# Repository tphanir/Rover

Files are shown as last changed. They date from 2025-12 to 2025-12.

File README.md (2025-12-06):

# Rover Genesis

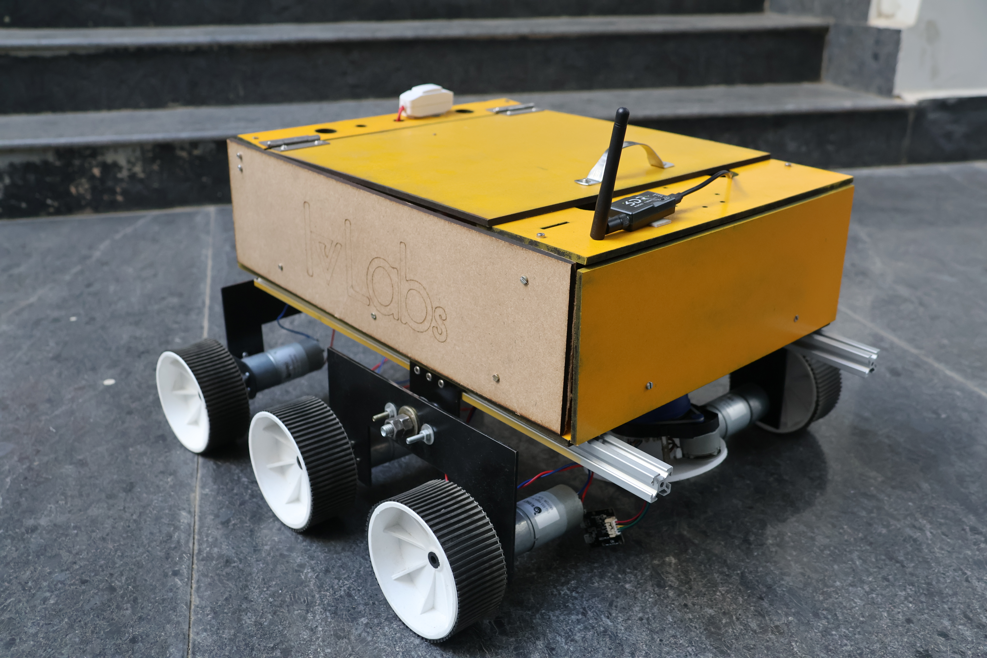
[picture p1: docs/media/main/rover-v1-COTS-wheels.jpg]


**Genesis** is a semi-autonomous rover platform designed for outdoor exploration, GPS-guided waypoint navigation, and obstacle avoidance. The system operates using a hybrid architecture: high-level computer vision and decision-making are handled by an **Nvidia Jetson Nano**, while real-time motor control and sensor integration are managed by an **Arduino Mega**.

The platform features a custom Base Station for telemetry and control, as well as voice-command capabilities for hands-free operation.

## Table of Contents

1. [System Architecture](#system-architecture)
2. [Project Structure](#project-structure)
3. [Key Features](#key-features)
4. [Hardware Specifications](#hardware-specifications)
5. [Getting Started](#getting-started)
6. [Usage](#usage)
7. [Documentation](#documentation)
8. [Contributors](#contributors)

---

## System Architecture

The software is divided into two primary nodes communicating via radio telemetry:

1.  **Onboard System:** Runs on the rover. Handles autonomous navigation logic, depth-camera processing, and hardware actuation.
2.  **Base Station:** Runs on a host laptop. Provides a GUI for manual control, mode switching (Auto/Manual), and live status monitoring.

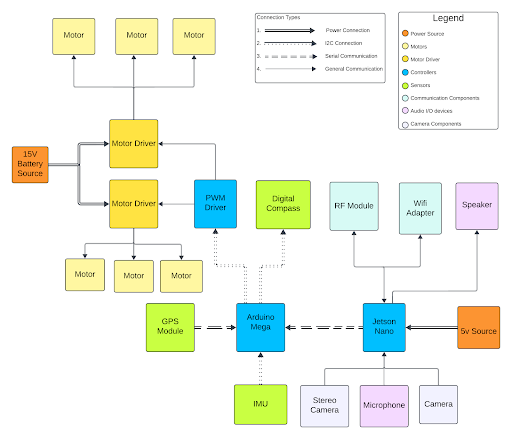
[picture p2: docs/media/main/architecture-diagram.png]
Architecture Diagram


---

## Project Structure

This repository is organized as follows:

* **`base_station/`**: Ground control software.
    * `gui/`: Contains Tkinter interface logic and configuration.
    * `run_station.py`: Entry point for the laptop control application.
* **`onboard/`**: The primary rover software (Jetson Nano).
    * `controls/`: Algorithms for GPS navigation (`gps.py`) and autonomous logic (`fullauto.py`).
    * `handlers/`: Interfaces for Serial communication (`mega.py`) and Manual control mapping.
    * `modules/`: Drivers for the RealSense camera (`camera.py`).
    * `main.py`: Entry point for the rover.
* **`extra/`**: Experimental scripts and isolated tests.
    * `detection/`: Standalone scripts for testing obstacle avoidance algorithms.
    * `imu/`: Visualization tools for sensor data.
* **`pcb/`**: Hardware design files.
    * Contains schematics and Gerber files for the custom power distribution board.
* **`docs/`**: Detailed documentation and media assets.

---

## Key Features

* **GPS Guided Navigation:** autonomous traversal to waypoints using the Haversine formula and magnetometer heading correction.
* **Vision-Based Avoidance:** Uses an Intel RealSense D415 to detect obstacles. The pipeline utilizes Canny Edge Detection and depth thresholding to identify hazards.
* **Voice Interaction:** Supports voice commands (e.g., "Stop", "Go") and Q&A using NLP models.
* **Telemetry:** Long-range 433MHz radio link for status updates and manual override.
* **Custom Electronics:** Features a dedicated PCB for efficient power management between the computing units and high-torque motors.

---

## Hardware Specifications

* **Compute:** Nvidia Jetson Nano (4GB) & Arduino Mega 2560
* **Vision:** Intel RealSense D415 Depth Camera
* **Sensors:** Ublox Neo M8N GPS, HMC5883L Magnetometer
* **Actuation:** BTS7960 43A Motor Drivers
* **Communication:** 3DR 433MHz Telemetry Radio
* **Power:** 4S LiPo Battery (14.8V)

For a detailed breakdown of the electronics, refer to `docs/hardware.md`.

---

## Prerequisites

* **Hardware:** A fully assembled Genesis rover and a host laptop.
* **Operating System:** Ubuntu 18.04 (Jetson Nano), Linux/Windows/MacOS (Base Station).
* **Python:** Version 3.6 or higher.

---

## Usage

### 1. Launching the Base Station
On your control laptop, connect the telemetry radio and run:

```bash
cd base_station
python3 run_station.py
```

### 2. Launching the Rover
SSH into the Jetson Nano or connect via terminal. Ensure the Arduino is connected via USB. Run:

```bash
cd onboard
python3 main.py
```

### 3. Operation Modes
* **Manual:** Use the WASD keys on the Base Station to drive the rover.
* **Auto:** Upload GPS coordinates via the GUI. The rover will calculate the bearing and distance, navigating autonomously while avoiding obstacles.

---

## Documentation
For deep dives into the specific algorithms and hardware designs, please refer to the `docs/` folder:

* **[Software Manual](docs/software.md):** Detailed explanation of the navigation math (Haversine), logic flows, and Vision pipeline.
* **[Hardware Guide](docs/hardware.md):** Wiring diagrams and component specifics.
* **[PCB Schematics](pcb/schematic.pdf):** Circuit diagrams for the custom board.

---

## Contributors
* Aiden Ross D'souza
* Telukunta Phani Raj
* Koyaneni Yashwant
* Shubham Pandere
* Yuvraj Gupta

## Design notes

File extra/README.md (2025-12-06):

# Extra / Experiments

This directory contains **miscellaneous experiments** and legacy code developed during the evolution of the **Rover** project.  
While not part of the main rover control system, these files served as important learning points for specific features, hardware integration, and testing.

---

## Overview

### `detection/`
- Contains multiple programs (`obstacle_x.py`) developed to test various Computer Vision (CV) methods for obstacle detection.
- **Requirement:** Intel RealSense camera.

### `imu/`
- Contains the IMU visualization and orientation tracking code (`imu.py`).
- Visualizes 3D motion of the rover (roll, pitch, yaw) using **PyOpenGL** and **pygame**.
- **Modes:**
  - **Connected:** Reads live orientation data from the ESP32-IMU.
  - **Disconnected:** Runs in simulation mode showing a static/rotating cube.

### `legacy/`
- Contains older versions of the main loop or scratchpad code (`main.py`) used for testing logic before integration into the `onboard` system.

### `serial/`
- Contains serial communication testing code (`radio.py`).
- Used to verify reading and relaying command data from the control computer (Base Station) via LoRa/Radio.

### `voice/`
- Contains standalone voice recognition tests (`voice.py`).
- Used to debug the voice command subsystem in isolation.

---

## Note
- None of these modules are required for the main rover execution.

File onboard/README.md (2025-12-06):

# Rover Main System

This directory contains the main control software for the Rover project.  
It integrates all modules needed for manual, semi-autonomous, and fully autonomous navigation, gps-based navigation.

---

## Overview

### controls/
Contains programs handling different control modes:
- **fullauto.py** — Full autonomous navigation using Camera. 
- **gps.py** — GPS control instruction program.
- **semiauto.py** — Semi-autonomous control combining user input with automation.

### handlers/
Handles inputs, communication, and command processing:
- **manual.py** — Manual (keyboard/joystick) control.  
- **mega.py** — Arduino Mega communication handler.  
- **serial.py** — Serial communication between base station and rover.  
- **voice.py** — Voice command handling.

### helpers/
- **forward.py** — Forwards messages from Arduion mega to base_station.

### main.py
- Main entry point — connects all modules for complete rover operation.

### modules/
- **Camera.py** — Camera handling and video stream processing.

### scripts/
- **docker.sh** — Docker script for setting up Jetson-Voice modules.
- **echo.sh** — Simply echoes the VoiceNav/data.txt content.

### voice_nav/
- **main.py** — Voice navigation control.  
- **data.txt** — Voice data or recognized commands.  
- **echo.sh** — Voice test script.

---

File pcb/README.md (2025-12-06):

# PCB Design & Hardware

This directory contains the manufacturing files for the custom **Power Distribution and Control Board** used in Rover Genesis 2. This board manages power delivery from the battery to the Jetson Nano, Arduino Mega, and motor drivers.

## File Overview

### `schematic.pdf`
The complete circuit diagram of the custom board. It details:
* **Power Regulation:** Buck converters for 5V (Jetson/Arduino) and 12V/VIN (Motors).
* **Pinout Connections:** Headers for connecting the Jetson Nano, Arduino, and sensors.
* **Protection:** Fuses and reverse polarity protection logic.

### `gerbers.zip`
The zipped Gerber files required for manufacturing the Printed Circuit Board (PCB). This file includes:
* **Copper Layers:** Top (GTL) and Bottom (GBL).
* **Solder Mask:** Top (GTS) and Bottom (GBS).
* **Silkscreen:** Component labels and logos (GTO).
* **Drill Files:** Hole locations and sizes (DRL).

## Fabrication Instructions

To manufacture this board, upload `gerbers.zip` to a PCB fabrication service (e.g., JLCPCB, PCBWay, OSH Park).

## Visuals
For 2D and 3D renders of this board, see the [docs/media/pcb](../docs/media/pcb) directory.

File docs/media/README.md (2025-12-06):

# Project Media & Assets

This directory contains visual assets and debug images used to document the hardware design and software logic.

## Directory Overview

### cad/ (Mechanical Design)
Contains renders from the CAD software used to model the chassis.
* **rover-v2-isometric-cad-model.png**: An angled 3D view of the complete rover.
* **rover-v2-top-cad-model.png**: A top-down view showing component placement.

### main/ (System Overview)
General images related to the rover architecture.
* **architecture-diagram.png**: A block diagram connecting the Base Station, Jetson Nano, and Arduino.
* **rover-v1-COTS-wheels.jpg**: A photograph of the assembled rover with COTS wheels.
* **rover-v1-3D-printed-wheels**: A photograph of the assembled rover with custom 3D printed wheels.

### obstacle_detection/ (Computer Vision Debug)
Visual outputs from the autonomous navigation module showing how the rover interprets depth data.
* **rgb-bbox.png**: Color camera feed with detected objects.
* **depth-bbox.png**: Depth map showing distance to objects.
* **threshold-map.png**: Binary image highlighting areas that are too close.
* **canny-edges.png**: Edge detection results used to define object boundaries.
* **obstacle-map.png**: The final processed map used for decision making.
* **decision-rotate-left.png**: Visualization of the logic deciding to turn left.

### pcb/ (Electronics)
Schematics and renders of the custom Power Distribution PCB.
* **2D-schematic-of-PCB-design.png**: The layout view of the PCB traces.
* **3D-schematic-of-PCB-design.png**: A 3D render of the manufactured board.

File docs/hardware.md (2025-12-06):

# Hardware & Electronics Specification

This document details the hardware architecture of the **Genesis** rover.

## Suspension System – Triple Bogie Configuration

The rover uses a **triple bogie suspension system** on each side, enabling high stability and smooth mobility over rough terrain. Each bogie can move independently, ensuring continuous wheel contact with uneven surfaces.

### Key Advantages

- **Terrain Adaptability:** Independent bogie movement keeps all wheels grounded, improving traction on rocks, slopes, and irregular surfaces.
- **Even Load Distribution:** Weight is shared across multiple wheels, reducing stress on individual components and increasing overall durability.
- **High Slope Stability:** The lowered center of mass and balanced weight distribution allow safe navigation on slopes up to **45°**.
- **Obstacle Handling:** The suspension can climb small obstacles and traverse gaps without wheel lift or instability.
- **Shock Absorption:** The interconnected bogies naturally dampen shocks, protecting onboard electronics and extending component lifespan.

## Wheel Design Comparison

Two wheel designs were evaluated: a **COTS (Commercial Off-The-Shelf) wheel** and an **in-house 3D-printed wheel**.

<p float="left">
  
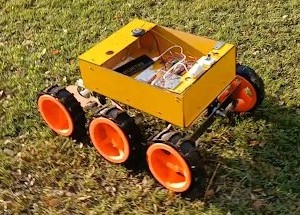
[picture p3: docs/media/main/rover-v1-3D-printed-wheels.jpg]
  
</p>

A summary of their performance is shown below:

### Table: Off-The-Shelf vs 3D-Printed Wheels

| Parameter | COTS Wheel | 3D-Printed Wheel |
| --- | --- | --- |
| Diameter | 10 cm | 22 cm |
| Width | 4.4 cm | 6 cm |
| Rover Speed | 20 cm/s | 44 cm/s |
| Grousers | Small | Large |
| Grip | Handles slopes up to 50° | Handles slopes up to 30° |
| In-Place Rotation | Smooth | Wobbly (Due to large grousers) |

## Electronic Components

The table below shows a comprehensive list of all electronic components used.

| Component | Purpose / Function |
| --- | --- |
| 14.8 V 4-cell Lithium polymer battery | Supplies power to the motor drivers |
| 5V Power Bank | Powers the Jetson Nano |
| Power Distribution Board | Distributes electrical power from the main source to the motor drivers |
| Customised PCB | Ensures stable connections between sensors and controllers |
| Jetson Nano (Student Developer Kit) | Primary processing unit for obstacle detection, voice commands, DetectNet, live streaming |
| Arduino Mega 2560 | Handles PWM signals, processes sensor data, communicates with peripherals |
| BTS7960 Motor Driver | Controls the movement of six motors |
| Orange OG555 DC Motor | Drives the rover’s wheels for movement and navigation |
| Ublox Neo M8N GPS Module | Provides real-time geolocation data for navigation and path planning |
| HMC5883L Magnetometer | Determines rover heading and maintains accurate orientation |
| YD LiDAR (2D LiDAR Sensor – 360° Scanning, 8m Distance) | Captures depth information for obstacle detection in a 2D plane |
| Intel RealSense D415 Stereo Camera | Captures depth information for obstacle detection in a 3D sphere |
| PlayStation Eye Camera | Provides visual feed for data collection and monitoring |
| 3DR 433 MHz Radio Telemetry | Enables wireless communication |
| Wi-Fi Adapter | Facilitates remote communication with the rover |
| Bestor Microphone | Records audio for audio-based functionalities |
| Speaker | Outputs audio feedback |

## Hardware Components

The table below shows a comprehensive list of all structural components used.

| Component | Material / Design | Features |
| --- | --- | --- |
| Chassis | High-quality acrylic held with L clamps | Durable and visually appealing design |
| Main Framework | 20×20 mm aluminum extrusions | Lightweight yet robust; maintains structural integrity while keeping weight manageable |
| Freely Moving Joints | Flanged ball bearings | Reduces friction and wear; allows smooth, efficient movement |
| Side Bogie Stability | Carbon fiber rods | High strength-to-weight ratio; reinforcement without added weight |
| Wheels | Durable COTF material (10 cm × 4 cm) | Ensures stability and smooth navigation across various terrains |
| Chassis Base | 5 mm MDF board | Adds strength and stability; reliable support for components |
| Side Bogie Construction | Mild steel | High strength and resistance to bending; improves slope-climbing capability |

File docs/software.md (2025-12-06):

# Genesis Rover: Software & Algorithms Manual

This document details the software stack, algorithms, and logic flows powering the **Genesis** rover. It covers system architecture, autonomous navigation, AI interaction, and control logic.

## Table of Contents
1. [System Architecture](#1-system-architecture)
2. [Autonomous Navigation Algorithms](#2-autonomous-navigation-algorithms)
3. [AI & Interaction Stack](#3-ai--interaction-stack)
4. [Control Logic & Data Flow](#4-control-logic--data-flow)
5. [Streaming](#5-streaming)

---

## 1. System Architecture
The software is distributed across three processing units:

* **Nvidia Jetson Nano:** Handles high-level decision making, Computer Vision (RealSense), AI (Voice/Object Detection), and Host Communication.
* **Arduino Mega 2560:** Handles low-level motor control (PWM generation) and sensor interfacing (IMU, GPS, Magnetometer).

---

## 2. Autonomous Navigation Algorithms

### 2.1 GPS Guided Navigation
The rover navigates to specific waypoints using a continuous feedback loop.

**1. Position Determination:**
Latitude ($\varphi$) and Longitude ($\lambda$) are retrieved from the **Ublox Neo M8N** module.

**2. Bearing Calculation:**
The required heading ($\theta$) is calculated using the formula:

$$\theta = \text{atan2}(\sin(\Delta\lambda) \cdot \cos(\varphi_2), \cos(\varphi_1) \cdot \sin(\varphi_2) - \sin(\varphi_1) \cdot \cos(\varphi_2) \cdot \cos(\Delta\lambda))$$

**3. Distance Calculation (Haversine Formula):**
The distance ($d$) to the target is computed to check if the rover has arrived within the acceptance radius:

$$a = \sin^2(\Delta\varphi/2) + \cos(\varphi_1) \cdot \cos(\varphi_2) \cdot \sin^2(\Delta\lambda/2)$$
$$c = 2 \cdot \text{atan2}(\sqrt{a}, \sqrt{1-a})$$
$$d = R \cdot c$$

*(Where $R \approx 6,371$ km)*

**4. Compass Alignment:**
The rover compares the calculated Bearing against the **HMC5883L Magnetometer** heading and rotates the chassis until they align.

### 2.2 Obstacle Avoidance (Vision Pipeline)
Uses an **Intel RealSense D415** Depth Camera. The processing pipeline is as follows:

1.  **Preprocessing:**
    * **Decimation Filter:** Downsamples image to reduce noise.
    * **Spatial Filter:** Smooths data and fills small holes.
    * **Thresholding:** Pixels > 1.0 meter are filtered out to focus on immediate hazards.
2.  **Canny Edge Detection:**
    * **Gaussian Blur:** Reduces noise.
    * **Gradient Calculation:** Finds intensity changes.
    * **Non-Maximum Suppression:** Thins edges.
    * **Double Thresholding:** Classifies strong/weak edges.
    * **Hysteresis:** Connects weak edges to strong edges.
3.  **Avoidance Logic:**
    The system calculates the "Center of Mass" of detected obstacles to decide the steering direction:
    * **Left Obstacle:** Rover turns **Right**.
    * **Right Obstacle:** Rover turns **Left**.
    * **Clear Path:** Rover moves **Forward**.

---

## 3. AI & Interaction Stack

### 3.1 Object Detection
* **Model:** SSD-MobileNet-v2.
* **Dataset:** MS COCO (91 Classes including Person, Vehicle, Animal, Household items).
* **Optimization:** Uses **TensorRT** for real-time inference on the Jetson Nano.

### 3.2 Voice Interaction
The voice system enables hands-free control and Q&A.

* **ASR (Automatic Speech Recognition):**
    * **QuartzNet-15x5:** For full sentence transcription.
    * **MatchboxNet:** For command classification (Keywords: "Stop", "Go", "Left", "Right").

* **TTS (Text-to-Speech):**
    * **FastPitch:** Generates MEL spectrograms.
    * **HiFiGAN:** Vocoder that converts spectrograms to audio.

---

## 4. Control Logic & Data Flow

### 4.1 Manual Mode
1.  **GUI Input:** User presses `W`, `A`, `S`, `D` on the Base Station.
2.  **Telemetry:** Signal sent via **3DR 433MHz Radio**.
3.  **Decoding:** Jetson Nano interprets signal.
4.  **Execution:** Arduino Mega receives command $\rightarrow$ PCA9685 PWM Driver $\rightarrow$ BTS7960 Motor Driver.
---

## 5. Streaming (Planned)
Video is streamed from the onboard webcam/RealSense to the Base Station using **RTP (Real-time Transport Protocol)** over Wi-Fi for low-latency feedback.

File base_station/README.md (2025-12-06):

# Base Station Control Panel

The **Base Station** is the mission control software for the Rover. It provides a GUI to send commands, switch autonomous modes, and view status updates.

## Structure
* **`run_station.py`**: The main entry point script.
* **`gui/`**: Contains the Tkinter source code, button logic, and serial handlers.

## How to Run

1.  **Dependencies**:
    Ensure you have Python 3 and the required libraries:
    ```bash
    pip3 install pyserial pillow
    # Tkinter is usually included with Python
    ```

2.  **Launch**:
    From this directory, run:
    ```bash
    python3 run_station.py
    ```

3.  **Usage**:
    * Select the correct COM port (e.g., `/dev/ttyUSB0` or `COM3`) and click **Refresh**.
    * Choose a mode (Manual, Auto, etc.).
    * Use **WASD** keys for manual driving.

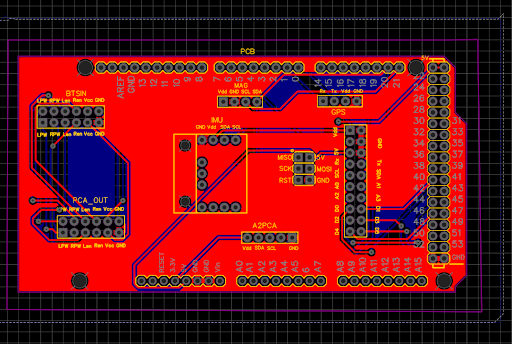
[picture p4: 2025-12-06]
docs/media/pcb/2D-schematic-of-PCB-design.png

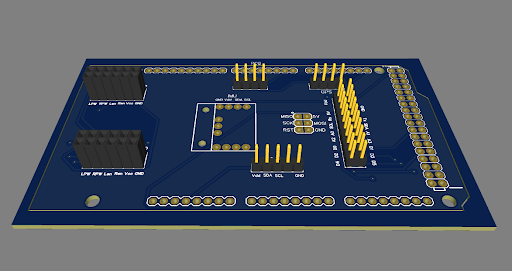
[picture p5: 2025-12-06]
docs/media/pcb/3D-schematic-of-PCB-design.png

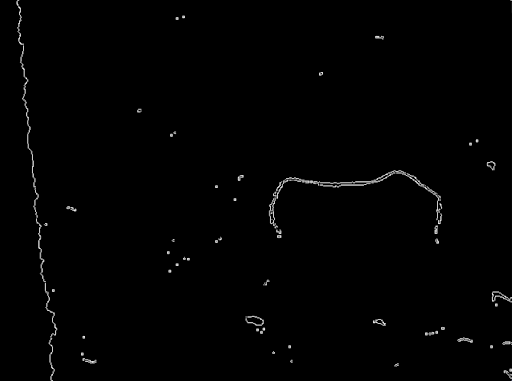
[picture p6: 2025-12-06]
docs/media/obstacle_detection/canny-edges.png

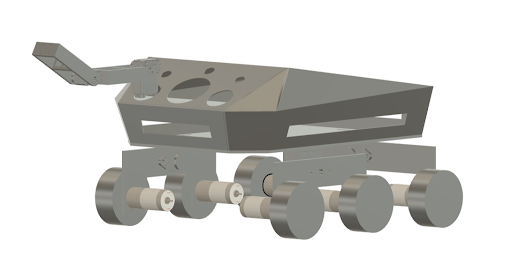
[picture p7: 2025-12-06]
docs/media/cad/rover-v2-isometric-cad-model.png

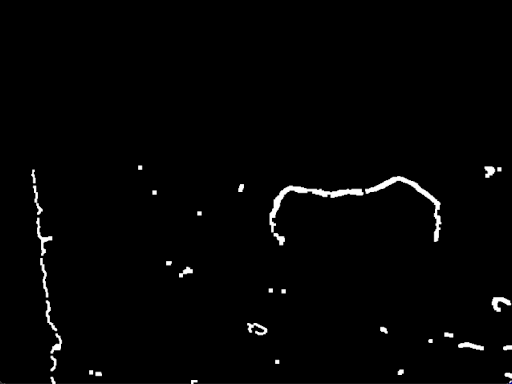
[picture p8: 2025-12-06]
docs/media/obstacle_detection/obstacle-map.png

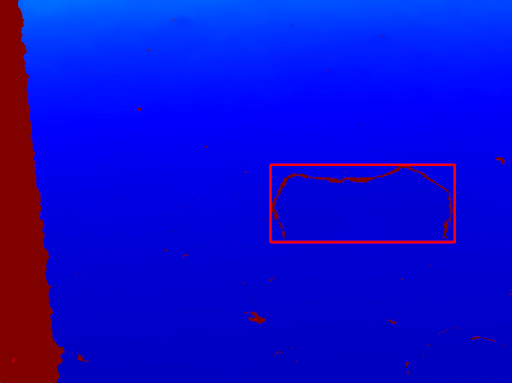
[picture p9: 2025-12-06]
docs/media/obstacle_detection/depth-bbox.png

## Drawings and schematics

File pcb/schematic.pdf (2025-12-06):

A | A

1

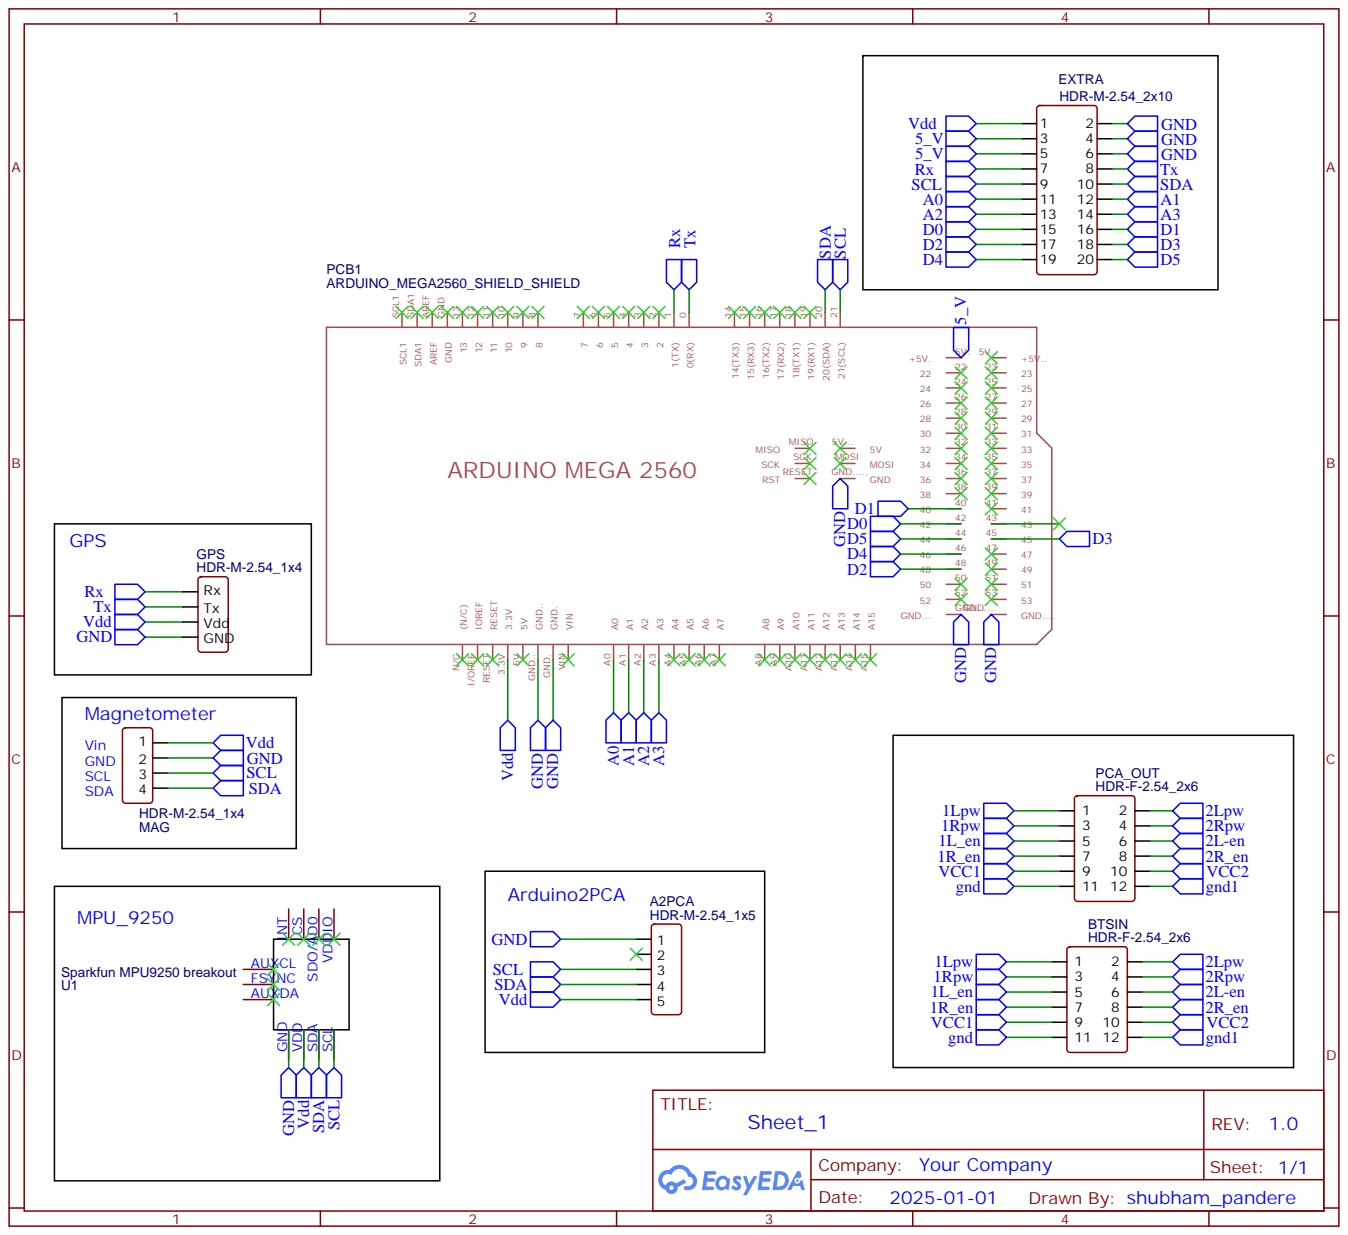
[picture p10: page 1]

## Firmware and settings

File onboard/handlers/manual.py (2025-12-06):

def manual(radio, mega):
    while True:
        # Get input from the user
        if radio.serial_connection.in_waiting > 0:
            command = radio.serial_connection.readline().decode('utf-8').strip()
            
        # Map commands to robot actions
            if command == 'W':
                mega.write(f"f\n".encode())
            elif command == 'A':
                mega.write(f"l\n".encode())
            elif command == 'S':
                mega.write(f"b\n".encode())
            elif command == 'D':
                mega.write(f"r\n".encode())
            elif command == 'X':
                mega.write(f"s\n".encode())
            elif command == 'return':
                mega.write(f'return\n'.encode())
                break

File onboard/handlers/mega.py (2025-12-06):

class MegaHandler:
    def __init__(self, port, baud_rate=115200, timeout=1):
        """
        Initialization
        """
        
        self.serial_connection = serial.Serial(port, baud_rate, timeout=timeout)
        self.running = True 
        print(f"Connected to Mega on {port}")

    def read_serial(self):
        """
        Continuously read from the serial connection.
        """
        
        while self.running:
            if self.serial_connection.in_waiting > 0:
                line = self.serial_connection.readline().decode('utf-8').strip()
                print(f"Received: {line}")

    def stop(self):
        """
        Stops the thread and closes the serial connection.
        """

        self.running = False
        time.sleep(0.5)  
        self.serial_connection.close()
        print("Serial connection closed.")

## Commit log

2024-12-16 Obstacle Tracel added
2025-10-28 Added PCB schematic and other media
2025-10-28 Added PCB gerber files
    [Drill_NPTH_Through.DRL, Drill_PTH_Through.DRL, Drill_PTH_Through_Via.DRL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]
2025-10-28 Added zipped Gerbers
    [Drill_NPTH_Through.DRL, Drill_PTH_Through.DRL, Drill_PTH_Through_Via.DRL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]
